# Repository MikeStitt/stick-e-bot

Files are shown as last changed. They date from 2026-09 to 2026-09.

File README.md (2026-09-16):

# stick-e-bot — a CAD course in Onshape

An introduction to Onshape, taught by building a printable stick figure robot
about 300 mm tall, with a ball-and-socket neck and hips and a ratcheting hinge at
the elbows and knees.

## Repository layout

```
CLAUDE.md                  The agreement to follow the Constitution, for AI assistants.
README.md                  This file.
build.ninja                `ninja check` — wrap, spelling, reading level and capture, in one
                           command. `ninja guides` builds the Sphinx sites.

instructions/              What a student or a teacher is handed.
  robot-guide/             The design source. make_plans.py renders every plan drawing from the
                           numbers, so a dimension is changed in one place.
  stickbot-draft9p4/       The guide in progress: fourteen tutorial pages and their frames.
docs/                      Background for those same people: how things work, what things are.
src/stickbot/              The Python, installed into .venv by `uv sync`: the four checks, the
                           design source, and the browser and API machinery. Imported by name —
                           nothing here or anywhere else touches sys.path.

.claude/rules/             The contract. Injected into an agent's context on every request.
  constitution.md          How material gets written and verified. Read first.
  parts/prose-style.md     How every word in this repository is written.
  parts/plan-activation.md How a plan becomes the active one, and how it stops being.
  active-plan.md           One import naming the plan being executed, empty when none is.
.claude/skills/            The rest of the contract. Read the one your task needs.
  onshape/                 Shared modeling and step-writing conventions.
  lesson-design/           Shared session-design rules: pacing, floor/ceiling, checkpoints, rubrics.
  modeling-practice/       The design-intent standard every reference model must meet.
  constitution-maintenance/  How the Constitution is amended, and its changelog.
.docs/                     For the people building the class, and for agents. Working notes,
                           design decisions, and the build specification under .docs/build/.
  experiments/runs/        One folder per draft: its plan, its notes, its logs, its register.
```

## Images

**A frame reaches git only by being placed on a guide page.** `.gitignore` denies raster images and
video everywhere and un-ignores exactly `instructions/*/source/images/`; a take writes its interim
capture to the session scratchpad, which is outside this tree. `src/stickbot/check_images.py` is the
*Capture is out* Quality Gate and checks that it happened, so a file added with `git add -f` is
caught too.

The repository this one replaces committed 12,977 screenshots totaling 1,651 MB because capture and
publication shared a directory. It sits beside this one and keeps that history;
[`.docs/2026-09-14-move-to-stick-e-bot.md`](.docs/2026-09-14-move-to-stick-e-bot.md) records what
moved and what did not.

## Getting set up

```sh
uv sync                            # the environment, from uv.lock
uv run playwright install chromium # separate step; uv sync does not do it
ninja check                        # wrap, spelling, reading level, capture
```

Every Python command in this repo is `uv run python …`.

## Reference models

The Onshape documents a session starts and ends from. Cite a **named version**, never the live
workspace; a workspace moves under the class.

| Document | Purpose | Link |
| --- | --- | --- |
| Instructor reference | The finished model, built the taught way | _TODO_ |
| Session 2 start | Recovery point: end-of-session-1 state | _TODO_ |
| Session 3 start | Recovery point: end-of-session-2 state | _TODO_ |
| Session 4 start | Recovery point: end-of-session-3 state | _TODO_ |

These are placeholders, and there is a known obstacle in front of them. On 2026-09-14 a second
Onshape account was given the document and workspace id of `stickbot-draft9p4` and was refused:
*document does not exist or you don't have permission to access it*. So a link here will not work
until the document is deliberately shared, and no link goes in until it has been opened by an
account without ownership rights.

## Contributing

Read [`.claude/rules/constitution.md`](.claude/rules/constitution.md) in full, then the part or
skill for your work type. Work on a feature branch; never commit to `main`; push only when asked.

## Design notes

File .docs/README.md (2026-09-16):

# .docs — working notes

Notes from building the course material and the reference model. These are **working notes, not the
contract** — the contract is [`.claude/rules/constitution.md`](../.claude/rules/constitution.md). If
a note here ever conflicts with the Constitution, the Constitution wins and the note is stale.

Each file marks what was **verified** (performed and observed) versus **unverified** (believed but
not checked), because the difference is the whole point of the Quality Gates.

This page is also the working list. Not every file in this folder is named here — the ones below
are the ones the current work points at.

## What needs doing, and what needs improving

State of play for the robot, at the end of run 2 (2026-08-11): Session 1 is
`instructions/robot-guide/source/index.rst`, a Sphinx page covering the body and the face. Part
one has been built twice, Part two once, and each was corrected after the run that tested it —
so **no part has been rebuilt from the text as it now stands**, and a run 3 would be its first
test. The run 2 model measures right — eyes r5, mouth 20.000 overall, neck Ø12 — at version
`run2-session1-complete`; the ball-and-socket and hinge joints are built at named versions too,
with ids in [run 2's folder](experiments/runs/2026-08-11-run2/README.md).

**Run 3 was launched, mis-briefed and thrown out** (2026-08-12). Its three agents read a brief
README claiming an open conflict over limb sections that did not exist; `#limbD` had been
settled at 12 the previous day. They were stopped, and the documents `ball-socket-run3` and
`lesson-run3` are deleted. The briefs have since been rewritten —
[`experiments/build-briefs/limbs.md`](experiments/build-briefs/limbs.md) replaces the four
invented limb briefs, and every numbers table carries a Source column. What the launcher does
before the next attempt is [`2026-08-12-launch-gate.md`](2026-08-12-launch-gate.md);
[`experiments/run3-launch.md`](experiments/run3-launch.md) holds the old prompts and is stale
against both.

## The big one — design intent

Every sketch in the model is built through the REST API from absolute coordinates with `constraints:
[]`. Under-defined, magic-numbered, and exactly the habit the course exists to prevent — see
[`modeling-practice`](../.claude/skills/modeling-practice/SKILL.md). The guide therefore
*demonstrates* the anti-pattern while *describing* the right thing, which is the worst combination
available.

**This is now work, not research.** `BTMSketchConstraint` and the `LENGTH` dimension were read back
off a rectangle drawn and dimensioned by driving the GUI — see [`onshape-api.md`](onshape-api.md).
Constrained sketches can be written through the API today.

Two gates when it is done: every sketch reports **fully defined**, and changing one driving variable
produces a correctly proportioned figure rather than a pile of parts. Both are checkable from a
script, so build them into the capture run rather than eyeballing them.

## Measure `#collar` from the ball's center, so `#grip` stops moving parts

**Done on 2026-08-27 as
[draft9p1p1's A2](experiments/runs/2026-08-26-draft9p1p1/plan.md), in the design source.**
Recorded here because [A2](experiments/runs/2026-08-25-draft9p1/a2-fit.md) got half of what it was
after and the other half was still available. `#collar` is now `#ball / 2 + #wall` = **9.0**, which
is the collar's own radius: the socket goes as deep below the ball's center as it is wide from the
axis. The model still has to be edited — that is Phase B. What follows is why.

`collar blank` extrudes `#grip` one way and `#collar - #grip` the other, so the socket is `#collar`
tall from a mouth at `#grip` down to a root at `#grip - #collar`. **A2 asks that a printing
clearance not ripple into any other robot dimension, and both of those ends move when `#grip`
moves.** [C2](experiments/runs/2026-08-25-draft9p1/c/c2-driving.md) drove `#fit` from 0.08 to 1 and
measured it: the socket stayed 11.000 tall at every value, and the tops of `Foot`, `Gripper` and
`u limb` each rose 2.0312 with `#grip`.

**So `#collar` is now the distance from the ball's center to the bottom of the socket**, and it
goes in `collar blank`'s second position on its own rather than as `#collar - #grip`. The root is
fixed, only the mouth moves, and the parts the socket is added to keep their dimensions when the
fit changes.

What it follows through to:

- The socket's overall height becomes `#collar + #grip` = 10.9465 rather than a constant, so the
  trade is named rather than hidden: before, the tabs kept a constant free length and the parts
  moved; now the parts keep their dimensions and the tabs' free length varies with the fit.
- `#collar - #grip` appears three times in the model and always means *the ball's center to the
  root*, so all three become plain `#collar`: `collar blank`'s second direction, the foot's
  `#collar_down`, and — inside a longer expression — `u limb`'s rod, which is
  `#limbCenter - #collar + #grip - #limbD / 2` and loses its `#grip` term.
- **No consumer sketches on a socket face**, checked over the API on 2026-08-27: `head`, `foot`,
  `u limb` and `gripper` each take the socket by `importDerived` and place it with a mate connector
  or a transform. So re-basing moves expressions and nothing else, and there is no rebuild order to
  get right.
- The slit floor does **not** follow from this on its own, and an earlier version of this section
  said it did. A2 fixes the root; the floor hung off the mouth at `#grip` and would have kept
  moving. It took [A1](experiments/runs/2026-08-26-draft9p1p1/plan.md) dimensioning the floor at
  `#ball / 4` below the ball's center to fix it, and that also
  [made the cut a slot for its whole depth](experiments/build-briefs/ball-and-socket.md).

**The test it has to pass is the robot's height**: `#fit` and `#grip` change no dimension of the
robot once the socket's root stops moving. In the design source it now passes — the figure comes
out 317.000 rather than 317.0535, and it stays there at any fit. Phase C measures the same thing at
the model.

## Carry the useful half of the old Session 1 into the new one

`experiments/session-1-layout-and-torso/` (**A**) was superseded on 2026-08-10 by the commit
that wrote `instructions/robot-guide/source/index.rst` (**B**) — *"Rewrite session 1 to start
from a design plan, and build it as a Sphinx page"*. B has had two test runs since; A has not
been touched since it was written. Before A is retired, four things in it have no counterpart in B.

**Its whole teaching half.** B has no `lesson-design.md` at all — no clock, floor, ceiling or
rubric. Worth carrying across specifically:

- **"Draw it badly on purpose."** The instructor draws visibly crooked, then the room watches
  geometry move as constraints land. B has no instructor guidance of any kind, and this transfers
  straight to B's torso rectangle.
- **The three across-the-room assessment questions**, especially the third — *can the student say
  what would happen if one driving line moved?* B's "Change one number" section already performs
  that demonstration with no assessment framing around it.
- **The ceiling items** — Equal instead of separate dimensions, deliberate over-constraint to find
  the redundant one, driving dimensions from a variable.

**Construction geometry, which B assumes and never teaches.** A teaches it — `q` to toggle, `v`
Vertical, `h` Horizontal. B uses none of them, but `index.rst:309` says *"this is the argument for
the rule about construction geometry: do not draw a construction line where a real edge already
is."* Either teach the rule in B or drop the sentence that depends on it.

**Two warnings B lacks.** `shift+s` is **Point**, not Sketch — A warns, B just says to use the
toolbar. And "the block only grew one way — Symmetric was not ticked", which is in A's failure
table and missing from B's fourteen-entry one.

**The drag test as a habit.** A makes it a ritual: every sketch, every time. B drags a corner at
Step 2 and mentions blue endpoints, but never establishes it.

**Do not carry A's "Tab, not Enter" note.** B's second test run found dimensions need **Enter** —
Escape silently discards the typed value, which produced a 34.8 mm torso instead of 48. Tab applies
only inside feature dialogs. A's version is wrong.

## Coverage and correctness

- **Nobody has walked the click-path.** A script did. Pacing, wording, whether a twelve-year-old
  finds the Depth box — all unknown until someone runs a session.
- **Steps 3 onwards are photographed by opening features for editing**, not by creating them. Same
  dialog, same real values, but never a half-finished selection. This is the main thing to revisit
  if the middle sessions feel thin. Steps 1 and 2 are driven click by click.
- **The fillet radii are the fragile dimensions.** A radius has to fit the face it rounds, so the
  guide's claim that any size of figure works with these steps is only tested at one size. Either
  test the range or stop claiming it.
- **Mirror is unverified and unused.** The build does everything twice by hand, which is the wrong
  lesson; Mirror is currently parked as a stretch task. Its `command-id` is known
  (`SKETCHMIRROR`, `mirror`), its dialog is not.
- **The appearance menu wording is unverified.** The highlight matches `[Aa]ppearance` loosely
  because the exact item text was never read.
- `README.md`'s reference-model links are still `_TODO_`. The document IDs are in
  [`project.md`](project.md).
- **`docs/` needs its second page.** The first is
  [`what-you-are-building.md`](../docs/what-you-are-building.md) — the robot, Onshape's
  vocabulary, and versions, written for a student and clean at grade 8. What is not covered
  yet: anything about printing the parts, and anything about the assembly.
- **Session 1's lesson-design exists now**, at
  [`../instructions/robot-guide/lesson-design.md`](../instructions/robot-guide/lesson-design.md),
  and it carries the teaching half salvaged from the old session. Two salvage items still belong
  in `source/index.rst` rather than the plan: the *Symmetric was not ticked* failure, and the
  decision on construction geometry — the page refers to a rule about it at line 309 and never
  teaches it.
- **The constitution review's 19 findings are unremediated.** The adversarial review ran on
  2026-08-12 against `e8508af`, `fffec7c` and `cb5ab99`, and nothing was applied — the last
  commit touching `constitution.md` or `.parts/` predates it. The findings, the three I contested,
  how a second round ruled on them, and the outstanding list are in
  [`2026-08-12-constitution-review-report.md`](2026-08-12-constitution-review-report.md). The
  cheapest item on that list is re-wrapping `constitution.md` to 100 columns: while it is red,
  `ninja check` never reaches the spelling and reading-level gates.
- **The build videos are a record of a build, not a lesson.** `instructions/robot-guide4/` now
  links a clip at the end of each block of steps, captured by `rec.py` as CDP event frames while
  the harness drove Onshape. They are honest and they are not yet teaching: the pointer jumps
  rather than moves, values appear in boxes already fully typed, there are long dead waits where
  the harness was blocked on a server round trip, and nothing names what is happening or why.
  The link text says *similar steps* because that is all they are — the clip covers the same
  ground as the pictures above it, not the same clicks in the same order. What would make them
  work for a student: a pointer that travels and pauses where a hand would, typing shown as
  typing, the dead time cut, a caption or a title card per step, and a decision about whether
  each clip covers one step or one section. Until then the pictures are the instruction and the
  clip is a second look. See
  [`experiments/runs/2026-08-19-run8p1/register.md`](experiments/runs/2026-08-19-run8p1/register.md).
- **The reviewer pass has not been run.** A different review from the one above, and Phase 3 of
  the reorganization. A reading pass, not a script: **Fable** reads the repository's prose —
  `.claude/rules/`, `.claude/skills/`, `instructions/`, `docs/`, `.docs/` and both READMEs — and
  flags three things.
    - **Unprofessional statements.** Snark, in-jokes, dismissiveness — anything that would not
      survive being read aloud to the class, or to a parent.
    - **Judgments based on age.** Text that sorts people by age and then uses the sorting to
      decide something. The same move made with grade level is in scope.
    - **Judgments based on status.** The same move made with standing rather than age —
      seniority, credentials, prior tool experience, or whether someone counts as a beginner.

  **What is flagged** — an age, grade, or standing substituting for a capability, an audience, or
  a permission. **What is not** — naming who is actually in the room. "Students range from
  middle-schoolers who have never opened a CAD tool to high-schoolers with some Fusion behind
  them" reports the roster. "A fourteen-year-old would not follow this" judges a person by their
  age. The first is a fact about the class; the second is a guess about a reader.

  **What it produces.** Every file is committed first, so Fable's changes land as a clean diff
  against a known state. Fable then edits in the working tree — the diff is the proposal — and
  writes `.docs/<YYYY-MM-DD>-professional-review-report.md` recording what it changed and why.
  **Nothing it writes is adopted by being written**: the diff gets read hunk by hunk, keeping what
  is right and reverting what is not, and the report is what explains a hunk when the change alone
  does not.
- **The explanatory sketches are not derived, and two of them argue for a decision rather than
  describing the design.** `experiments/sketches/`'s three studies type their inputs where the
  hinge review generates everything it shows. What to do about that, and the distinction between a
  figure that must be regenerated and one that must not, is in
  [`2026-09-16-derived-figures.md`](2026-09-16-derived-figures.md).
- **Four Stage 5 teaching routes lost their home when the limbs became cylinders.** `#limbD` is
  12 and every limb is a Ø12 cylinder, so the limb rows in the Stage 5 build order —
  [`robot-build-plan.md:609`](robot-build-plan.md) and `:611` — no longer describe a part anyone
  will model. What that costs, against the coverage table:
  - **Parallel** (`:689`) and **Perpendicular** (`:690`) are earned only in **set-piece 1**, the
    sloppy quadrilateral squared by constraints, which was the shin.
  - **Sketch Fillet and Chamfer** (`:674`) is earned only on that same quadrilateral's corners.
  - **Loft** (`:707`) is earned only on the upper arm's ellipse-to-rounded-rectangle change of
    section.
  - **Ellipse** (`:665`) and **Lines and Rectangles** (`:661`) survive — the eyes and the torso
    rectangle each carry them without a limb.

  Each of the four needs one of three answers: rehome it on a part that still needs it, teach it
  on a scratch sketch that is not a robot part, or drop it from the curriculum and say so. This
  is a curriculum decision. **Do not shape a limb to keep a tool** — where a route cannot produce
  a Ø12 cylinder, the route gives way. See
  [`experiments/build-briefs/limbs.md`](experiments/build-briefs/limbs.md), which is written not
  to answer this.
- **Two constitution amendments are pending, both from the same failure.** Read
  [`constitution-maintenance`](../.claude/skills/constitution-maintenance/SKILL.md) before making
  them.
  - **Reading the specification is a verification step.** *Verification is evidence, not
    assertion* covers building the thing and looking at it; it does not say that the relevant
    specification and requirements MUST be read first. Add that, and attach it to the same list
    of activities as Working Rule 1 — before you plan, write, model, code **or direct**.
  - **`direct` belongs in every enumeration of what an agent does.** Working Rule 1 says "think
    before you write, model, or code"; the Quality Gates and *Verification is evidence* are
    written for someone doing the work with their own hands. Directing a subagent is none of
    those verbs, and it is how most of the work now happens. Every list of activities in the
    Constitution needs it.

  *Why:* three agents were launched against briefs written without reading the settled spec. The
  limbs had been fixed at Ø12 the previous day — decided in conversation, recorded in the hinge
  brief, in no document the launcher read — and the briefs invented sections that contradicted
  it. Nothing verified the direction, because no rule treats directing as work.
- **Session 1's two documents are reconciled.** `instructions/robot-guide/` supersedes
  `experiments/session-1-layout-and-torso/` — what to salvage from the older one is above, under
  *Carry the useful half of the old Session 1 into the new one*.

## Pipeline improvements worth making

- **`show_result` reopens the document** to get a known camera, which costs a 16 s page load each
  time. Correct, but it is most of the runtime of a capture run. A cheaper deterministic camera
  would pay for itself.
- **Onshape rate-limits hard.** A burst of feature writes earns a 429 on that endpoint family that
  took over an hour to clear on one occasion, blocking all capture work. Writes are paced now, but
  do not plan a working session around many rebuilds.
- **Handling a 429 is written, and the history says why it took eight tries.** Done on 2026-08-28.
  The rule is [`onshape`](../.claude/skills/onshape/SKILL.md) § *Read what a refusal says before
  waiting on it*; the mechanism is `api()` in
  [`../src/stickbot/onshape_session.py`](../src/stickbot/onshape_session.py), which now keeps the
  response headers, honors a short `retry-after`, and raises at once rather than spending a ladder
  to discover the answer is hours away.

  **Verified against a live 429 on 2026-08-28.** `features` answered `retry-after: 522` with
  `x-rate-limit-remaining: 0`, and `api()` raised in 0.10 s naming both, where the old ladder
  would have spent 110 s and five requests to reach a message that was wrong on two counts. In
  the same pass `bodydetails`, `parts` and `assemblies` answered 200 with 486, 500 and 1000 calls
  left, which is the per-family limit measured from the healthy side. The sweep of what came
  before:

  - **08-10, `5263ee7`, the client's `api()`.** Assumed one kind of 429, minutes long, and
    laddered 5 s to 480 s, 955 s in all. It was the first handling of any kind: before it a 429
    read as a `DELETE` that quietly did nothing and a feature list with no `features` key.
  - **08-10, `b5d2aec`, the same function.** Cut the ladder to 5, 15, 30, 60 because *"an
    unbounded backoff turns a rate limit into something indistinguishable from a freeze"*. The
    reasoning holds. The message did not: it hard-coded *"account-wide on the feature endpoints
    and clears in minutes"*, and that sentence is what every later reader believed.
  - **08-10, `be1b460`, `wait_and_capture.py`.** Polled every 60 s and gave up after an hour. A
    runner that waits, for a limit whose answer is a different route.
  - **08-10, `08a50d2`, the same runner.** Polled every 300 s and gave up after six hours, on the
    theory that the polling itself was holding the block open. Six hours does not outlast
    eighteen. Retired on 08-12 with the pipeline that used it.
  - **08-13, `60377ea`, `design-into-cad.md`.** Right, and complete: a daily quota, `retry-after`
    in the tens of thousands of seconds, counting down with the clock, one endpoint throttled
    while the rest answer, so move to the GUI. Prose only. It landed in `.docs/experiments/`,
    which the Constitution files as archive, and no code and no part changed.
  - **08-14, `013b57f`, `onshape-gui-howto.md`.** Took 83 s from the one end-to-end pair in run
    3's torso log and made it the recovery time. One measurement of the short mode, generalized.
  - **08-14, `905fff0`, the same file, hours later.** Corrected itself: two kinds, waiting inside
    a session worked neither time, plan a route that avoids `/features`. Still prose only.
  - **08-24, `15441c6`, tutorial 11's build log.** Backed off every time and it did not clear, so
    `featureStatus` was never read; the acceptance check fell back to looking for error badges in
    the tree frame.
  - **08-27, draft9p1p1 Phase C.** Measured all of it from scratch again, and re-planned a phase
    around never touching `features`.

  **The cause is not that nobody knew.** It was right in the tree on 08-13, fourteen days before it
  was measured again, and re-derived on 08-14. What failed each time is that the finding landed in a
  working note while the client went on asserting the opposite in the message it raised, and the
  client is what the next person read. A finding about a tool has to reach the tool.
- **Arc and circle have never been drawn from a script.** Rectangle and dimension have. Same shape
  of problem, and needed if more steps are to be driven click by click.
- **The browser profile lives in a session scratchpad**, so the login does not survive. Move it
  somewhere durable, or get an API key from `dev-portal.onshape.com` and stop depending on a
  signed-in window.
- Three stale Onshape documents can be deleted once nothing points at them — see
  [`project.md`](project.md).

## Future work — print orientation, and the edge treatments that depend on it

**Not adopted. Recorded because it blocked a decision we tried to take on 2026-08-11.**

We went looking for a standard fillet size for a 0.4 mm nozzle and found the question is not
answerable on its own. Every useful source qualifies its advice by which way the feature faces
on the plate:

- **Vertical corners are already filleted at about 0.2 mm** — half the nozzle diameter — whether
  drawn or not. Protolabs Network: *"Because FDM printing nozzles are circular, corners and
  edges have a radius equal to the nozzle size."* So nothing below ~0.4 mm is worth drawing.
- **Downward-facing fillets print badly** and want to be chamfers instead. Hydra Research: *"do
  not use downward facing fillets… they may come out with poor aesthetic/surface quality."*
- **Edges on the build plate want a 45° chamfer**, sized 0.3–1.0 mm depending on layer height.

Candidate numbers, if we ever adopt them: **0.5 mm × 45° for a cosmetic edge break, R1.0 as the
minimum drawn fillet, and nothing under 0.4 mm drawn at all.**

**Why it is not adopted:** "upward" and "downward" are properties of the print, not of the
model. Until each part carries a **declared print orientation**, an edge rule cannot be applied
— the same fillet is fine on one face and ugly on the opposite one.

**The bigger instance of the same problem is structural, not cosmetic.** A snap-fit tab flexed
about an axis parallel to the layer lines peels them apart and fails well below the calculated
strain; flexed within a layer it does not. That applies directly to the ball socket's four tabs
and to the hinge's sprung ears, and neither brief says which way up the part is printed. The
hinge report's 2.2 % ear strain and the socket's tab calculations both quietly assume the
favorable orientation.

**What adopting it would take:** a declared orientation per part, shown on the parts drawing;
edge treatments chosen per edge against that orientation; and the tab-bearing parts oriented so
their tabs flex in-layer.

Sources: [Protolabs Network](https://www.hubs.com/knowledge-base/how-design-parts-fdm-3d-printing/),
[Hydra Research](https://www.hydraresearch3d.com/design-rules),
[NExT Lab](https://ms-kb.msd.unimelb.edu.au/next-lab/3d-printing/design-guidelines),
[3DVerkstan](https://support.3dverkstan.se/article/38-designing-for-3d-printing).

## Decisions taken, worth not re-litigating

- **Highlights come from the DOM.** No pixel coordinates anywhere. This is what keeps the
  annotations correct across window sizes and Onshape's redesigns, and it was the single most
  useful decision in the project.
- **Every shot verifies itself.** A click that should select something is checked against Onshape's
  own measurement readout; a highlight target that is not on screen raises rather than quietly
  vanishing.
- **The builder only ever goes forwards.** Rebuilding the figure per step would be ~500 feature
  writes and a guaranteed rate limit; building forwards is 22.
- **Screenshots notice, measurements conclude.** See
  [`verification-lessons.md`](verification-lessons.md) — three wrong diagnoses in one session came
  from treating a surprising picture as evidence of its own cause.

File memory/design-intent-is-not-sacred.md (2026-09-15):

---
name: design-intent-is-not-sacred
description:
  "No design source outranks another; a constraint that is causing disproportionate work is itself
  the suspect."
metadata: 
  node_type: memory
  type: feedback
  originSessionId: c7e95b50-7b3c-4747-a656-ece9f33b51c4
  modified: 2026-08-13T20:02:09.527Z
---

Never rank the design sources against each other — sketches, briefs, and whether the thing
actually assembles and articulates all sit at one level. When a requirement is costing
disproportionate work, treat the requirement as a candidate for change, not just the work.

**Why:** ranking makes one source unchangeable, and an unchangeable source turns every conflict
into work squeezed around it. The reference robot's "150 mm tall" is the worked example: while it
was a requirement the design bent to reach it, and once the parts were allowed to fall where the
joints put them the problem got smaller and the answer got honest. How much work a constraint is
causing is evidence about the constraint.

**How to apply:** when a conflict appears, say what it would cost to change each side, including
the requirement itself — do not silently treat the stated number as fixed and optimize around it.
Present changing the requirement as a real option with its price. Related: the user still decides
— see [[instructions-state-facts-not-importance]] and [[cad-models-need-design-intent]], which is
about a model surviving a driving-dimension change, not about which dimension is allowed to drive.

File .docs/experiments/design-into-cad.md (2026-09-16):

# Getting the design into the CAD

After run 3 we changed the initial sketches and then the briefs. The design moved and the CAD did
not. The sketches were re-drawn, the shoulder was angled, the
hinge was rebalanced, and the briefs were corrected against measurement — none of which reached a
part studio. Run 4 copied run 3's geometry, added mate connectors, and assembled it; every sketch
and extrude in it is still run 3's. See
[`runs/2026-08-13-run4/build-notes.md`](runs/2026-08-13-run4/build-notes.md).

This file is the plan for closing that gap. It is deliberately two sections in one: a **high-level
plan** that does not change, and a **low-level plan** whose steps are chosen while the work is
running, from what each part turns out to contain.

It is the procedure, not the checks. [`build-and-verify.md`](build-and-verify.md) is the wave
cycle, [`build-briefs/README.md`](build-briefs/README.md) is what a part is held to, and the
Constitution governs sessions, versions, and branches.

## Done means

Every number and every shape the sketches and the briefs assert is **either in the CAD or written
down as an unresolved conflict**, and the assembly is rebuilt from the repaired parts.

We examine each part and the assembly in detail until we understand what every one of its features
is. We confirm from those features that it looks like the part the sketches and briefs asked for,
and specifically that it matches the developmental sketches the briefs were constructed from. We
measure the dimensions and confirm they match the briefs and the initial sketches.

For the assembly we confirm that its dimensions, orientation, parts and mates are right against
the briefs and the initial sketches.

---
# The high-level plan

## Authority

When two sources disagree, this is the order, and it does not get renegotiated per part.

| Rank | Source | What it settles |
|---|---|---|
| 1 | [`sketches/`](sketches/), [`build-briefs/`](build-briefs/), our evaluation of if the robot assembles and articulates per the design intent | pose, station, which way a part faces, what the figure looks like, each part's own numbers and its acceptance checks |
| 2 | the CAD | **nothing** — it is the thing under test |

**Sketch and brief can disagree with each other**, and when they do neither wins automatically —
that is a conflict for you to resolve in a way that achieves our design intent.

**They share a rank deliberately.** Ranking them would make one of them unchangeable, and an
unchangeable source turns every conflict into work squeezed around it. The figure's height is the
worked example: while 150 mm was a requirement the design bent to reach it, and once the parts
were allowed to fall where the joints put them the problem got smaller. No part of the design
intent is sacred. **How much work a constraint is causing is evidence about the constraint**, not
only about the work.

**A brief row marked *measured* or *built* is a record, not a target.** Some rows came back out of
the CAD rather than out of the design — the foot's collar reads `5.5 → 7.35 | plan, then built`,
because the collar's proud length is set by the plate and the foot cannot reach 5.5. Repairing to
a row like that models backwards from an accident, or chases a number the part cannot hold. Read
the **Source** column first: `plan` and `derived` are targets, `proposed` is a target nobody has
challenged, and `built` and `measured` are history.

## The phases

Mark each phase 'Done.' as completed.

0. **Copy.** Done. Nine documents copied to run 5, recorded in
   `runs/2026-08-13-run5/run5-documents.json`. All of this work happens in run 5.
1. **Gather a list of changes.** Done. `git diff 5ff5f3d..HEAD` over the briefs and the
   sketches, written to `runs/2026-08-13-run5/changes-since-run3.md`.
2. **State the target.** Done. `src/stickbot/make_target.py` writes
   `runs/2026-08-13-run5/target.json` from **both** sources: every design constant out of
   `make_plans.py` by introspection, and every numbers-table row out of the briefs by parsing
   — 91 numbers, the figure's stations, each joint in the frame its part is modeled in, and 64
   brief rows carrying their **Source**, classified target against record. Nothing is typed in,
   so neither half can drift. Briefs with no numbers table are named rather than dropped.
3. **Audit.** Done. All six parts measured and rendered in four views;
   `runs/2026-08-13-run5/audit.md` carries the deltas classified by route, and
   `measured.json` the raw faces and solids. Two parts need no repair.
4. **Deconflict.** Done. `runs/2026-08-13-run5/deconflict.md` — the hinge stack checked
   surface by surface across both halves, four things resolved, two registered.
5. **Repair.** Done. S1 through S5, each measured on solved geometry and written up in
   `runs/2026-08-13-run5/repairs.md`.
6. **Evaluate the parts.** Done. The three axes below, on the parts, in
   `runs/2026-08-13-run5/evaluation.md`.
7. **Re-assemble.** Done. Fourteen instances from `run 5` versions, thirteen mates, all `OK`,
   published as the `run 5 assembled` version of `lesson-run5`.
8. **Evaluate the robot.** Done. Same file — every station matches `make_plans.py`.
9. **Register.** Done. `runs/2026-08-13-run5/register.md`.

Run the phases in order, in this top-level agent, which does all of the CAD itself. It may give
analysis, research, evaluation and thinking to sub-agents.

**Do not stop between phases.** Finishing a phase is not a place to report and wait — mark it
Done, commit, and start the next one in the same breath. The run goes from phase 0 to phase 9
without being told to continue. This holds whether or not anyone is watching: an unattended run
and an attended one differ in who is reading, not in whether the work proceeds.

There is no question worth stopping for, because there is somewhere else for every question to go.
A conflict goes in the register with what it turns on and what the options cost; a decision that
is not mine gets its cheap answer written down and the work routes around it. Stopping to ask
converts a question that costs a paragraph into one that costs the rest of the run.

## The three evaluation axes

The user's three questions, and how each is actually answered rather than asserted.

| Axis | Answered by |
| ---- | --- |
| **Matches the sketches** | station and pose measured off the assembly — joint centers, overall height, arm span, which plane each part's length runs in — compared against `make_plans.py`'s own numbers, not against a reading of the drawing |
| **Matches the briefs** | each brief's *Acceptance checks* section, performed and recorded per part. They exist for this and were written to be measured, not inferred |
| **Works as a printable robot** | the three sub-axes below |

"Works" is the one that has no checklist yet, so it gets one:

- **Printable.** No wall below one nozzle width anywhere in the part; overhangs and bridges
  identified per part with the print orientation named; no feature that only exists in the model
  because the model has no gravity.
- **Assemblable.** Every ball can enter its socket — which means every socket collar is slit —
  and every press fit has an interference that is deliberate and stated. A joint that cannot be
  put together once is a failure even if it measures perfectly.
- **Functional.** Each joint reaches the range the sketch draws it at without fouling the part
  next to it, and each spring feature sits far enough below PETG's yield to survive a print that
  came out thick. The ranges and the margins are in the briefs; this axis is where they get
  checked against the assembled geometry rather than against a hand calculation.

## What gets resolved and what gets written down

**I resolve** a conflict when all three hold: the brief row is a target rather than a record, the
change moves no driving variable, and the fix does not trade one stated goal against another.
Slitting a collar, changing a thickness the brief already settled, rebuilding a feature to numbers
that are already derived — those are work, not decisions.

**I write down** — and do not decide — anything that moves a driver (`#torsoH`, `#hipHalf`,
`#legX`), anything where the sketches and the briefs disagree with each other, anything that
changes the part count or introduces handedness, and any fix that buys one axis by spending
another. Each entry carries what is known, what it turns on, what the options cost, and the cheap
answer, per the unattended rule in [`build-and-verify.md`](build-and-verify.md).

**A third case exists and has bitten once already:** work I did not attempt, recorded as though it
had been a decision. It is neither resolved nor a genuine conflict, and calling it parked is a
false record. If it was not attempted, the register says so in those words.

## Where the work lives

Repairs go into the **run 5 documents' workspaces**. Run 4 is left alone: it is the record of what
an assembly built from unrepaired parts measured, and run 5's instructions are what the teacher
and student will follow, so run 5 is the copy worth having.

---

# The low-level plan

The high-level plan is fixed. Everything from here is chosen at audit time, because what a repair
costs depends entirely on how the feature that needs repairing was built — and that is not known
until it is read.

## Repair routes

Every delta the audit finds is classified by the route that can fix it. Which route applies is a
property of how the part was built, not of the delta, and it is read off the feature tree.

| Route | Applies when | Cost |
| ----- | --- | ---- |
| **Variable** | the number is driven by a variable in the studio | one edit, propagates |
| **Feature parameter** | the number is a feature's own parameter — an extrude depth, a fillet radius, a pattern count | one call per feature |
| **Sketch entity** | the number lives in a sketch's geometry or its dimensions | the sketch's entities and constraints are rewritten together |
| **New feature** | the geometry does not exist at all, as with a collar that was never slit | insert at the right point in the tree, not at the end |
| **Rebuild** | the construction cannot express the target — a solid blade that has to become two tabs | delete and re-author the affected span |
| **GUI** | the API route fails, or the edit is faster by hand | screenshot it; run 5 needs the pictures anyway |

## The steps

Written by phases 1–4 and worked through in phase 5. Reasoning is not repeated here — each step
points at the file that carries it. Mark a step **Done** as it completes.

### S0 — prove the sketch-entity route — **Done**

Proved on `ball-socket-run5`, which no assembly instance references. The route works, and it is
not where it looks like it should be.

A sketch is a `BTMSketch-151`. Its `parameters` carry only `sketchPlane` and `disableImprinting`;
the geometry lives in the feature's own `entities` and `constraints` fields, in **meters**.

**Edit the dimension constraint, not the entity.** Setting `entities[0].geometry.radius` from
0.0047 to 0.0055 answered 200 and read back 0.0055 — and moved nothing, because a `DIAMETER`
constraint drives that circle and the solver puts the geometry back. Setting that constraint's
`length` expression from `9.4 mm` to `11 mm` moved the volume 2305.3461 → 2432.2462, and
restoring it came back to 2305.3461 exactly.

**So the entity's stored radius is stale cache, not the solved value**, and reading it back proves
nothing. This defeats read-back-plus-200 as a check: both passed on the edit that did nothing.
Only the measured quantity caught it. Every step below measures something that must move.

### S1 — torso: the shoulder stud and the neck boss — **Done**

Per [`audit.md`](runs/2026-08-13-run5/audit.md). Hardest, so it goes first. Built and measured in
[`repairs.md`](runs/2026-08-13-run5/repairs.md), which also carries the four findings. S1e closed
the other way: the neck boss cannot buy the tilt it exists for, so it is not built.

- **S1a** Shoulder stud on a doubly-rotated axis: 53° below horizontal, 30° toward the front,
  rooted on the side face at x = ±18, z = +20. The part has no plane for this — it needs a mate
  connector or a construction plane before it needs a sketch.
- **S1b** Ø8 boss, 8 long, coaxial with the stalk; then Ø3 stalk for the last 5; then the Ø6 ball.
  Ball lands at (±24.775, −3.912, +9.618).
- **S1c** Cut the boss flush where it crosses the torso's top face at z = +24.
- **S1d** Mirror to the left shoulder — mirror the part, not the feature.
- **S1e** Neck boss Ø12 on the top face, on the axis. New feature.
- **S1f** Measure the least clearance between the upper arm and the torso across the full
  ±37.09° swing. This is the check the geometry exists to pass.

### S2 and S3 — the two limb halves, together — **Done**

Measured in [`runs/2026-08-13-run5/repairs.md`](runs/2026-08-13-run5/repairs.md). S3c turned out to
be two features rather than one, and that record says which.

They meet inside one joint and the stack is checked in
[`deconflict.md`](runs/2026-08-13-run5/deconflict.md). Repairing one alone leaves a joint that
cannot close, so neither is Done until both measure.

- **S2a** `limb-socket-clevis`: slot half-width 1.8 → 2.8, so the ear becomes 3.2.
- **S2b** Remove the ear's outer planes at ±3.0 and ±2.5 — the ear's outer surface is the Ø12
  cylinder and has no outer plane at all.
- **S2c** Round ends r5.81 → r6, putting the fork tip at z = −30.
- **S2d** Stub inner face ±1.0 → ±2.0, keeping it 0.8 proud of the new ear face.
- **S2e** Slot root to z = −13, which is 11 behind the pin axis.
- **S3a** `limb-blade-ball`: blade half-thickness 1.5 → 2.5.
- **S3b** Detent valley floors ±1.05 → ±2.05; land follows the blade face to ±2.5.
- **S3c** Round end r5.81 → r6, blade tip at z = +6, blade's limb ending at z = −10.
- **S3d** The slit: 0.8 wide, 16 deep, down the blade's middle, open at the tip, leaving two 2.1
  tabs. New feature.

### S4 — foot — **Done**

Measured in [`runs/2026-08-13-run5/repairs.md`](runs/2026-08-13-run5/repairs.md).

- **S4a** Re-sketch the outline with its length along **Y**, symmetric about the Right (YZ) plane
  by `Symmetric` constraint rather than by dimensioning both sides.
- **S4b** Four relief slits, 0.8 wide, cut through the collar for its **whole 7.35** proud length
  — the slit follows the collar it is cut into, not `COLLAR_L`.

### S5 — the brief that is wrong, not the model — **Done**

- **S5a** `hinge.md` says run 3 built 13 detent valleys. It built 24 a side, and `STEP` 15 divides
  360 into exactly 24. Correct the brief.

### S6 — versions — **Done**

One named version per repaired part, cut after its measurements pass. The assembly cites versions,
never workspaces — so the two parts run 5 did not touch, the head and the hand, get one as well.
All six are named `run 5` and their ids are in
[`runs/2026-08-13-run5/run5-documents.json`](runs/2026-08-13-run5/run5-documents.json).

### S7 — assembly — **Done**

Rebuilt from the new versions and re-mated: thirteen mates, all `OK`. The foot's 90° turn came out,
because S4a puts the part's length on the axis the assembly wanted. The shoulders needed two new
mate connectors, placed in the assembly rather than the torso. Measured in
[`runs/2026-08-13-run5/repairs.md`](runs/2026-08-13-run5/repairs.md).

### S8 and S9 — evaluate and register — **Done**

The three axes on the parts and then on the robot are in
[`runs/2026-08-13-run5/evaluation.md`](runs/2026-08-13-run5/evaluation.md), and what was resolved,
what was not, and what was never attempted are in
[`runs/2026-08-13-run5/register.md`](runs/2026-08-13-run5/register.md).

## What the API is known to do

Stated precisely, because it was once asserted here more broadly than it had been tested.

| Operation | Endpoint | Status |
| --- | --- | --- |
| add a feature | `POST .../partstudios/d/{d}/w/{w}/e/{e}/features` | **proven** — run 4's mate connectors |
| update a feature's parameters | `POST .../features/featureid/{fid}` | **proven** on an extrude — see below |
| rewrite a sketch's entities and constraints | same endpoint, different payload | **proven** — see below |
| insert a feature mid-tree | `POST .../features/rollback`, then add, then move the bar back | **proven** — S1 put four features between a revolve and its mirror |
| read every feature's parameter spec | `GET .../featurespecs` | **proven** — how S1 learned `transform` without opening the GUI |
| delete a feature | `DELETE .../features/featureid/{fid}` | proven on assembly features; the id must be percent-encoded, because ids contain `/` |
| read every face's surface, radius, axis, area and box | `GET .../parts/d/{d}/w/{w}/e/{e}/partid/{p}/bodydetails` | **proven** on all six parts, and **not rate limited** while `featurescript` was 429 — it answered most of the acceptance checks |

**A feature is always added at the rollback bar**, and the bar has its own call. `rollbackIndex`
passed in the add body is ignored without complaint — the feature lands at the end and the answer
is still `200`.

The update test, run on the `ball-socket` study document because no assembly instance references
it: the `Socket collar` extrude's depth was round-tripped unchanged, then driven 1.35 → 9.5, then
restored. All three answered `200`, the parameter read back changed, and total solid volume moved
2305.3461 → 2681.2635 → 2305.3461 mm³. The study is back where it started.

**A `200` is not the test.** The first attempt measured overall height, which sat at exactly 150.0
before and after because a reference body sets it — the call looked successful and proved nothing.
Every repair re-reads the changed parameter *and* measures a quantity that must move.

### Sketches

A sketch is a `BTMSketch-151`. Its `parameters` carry only `sketchPlane` and `disableImprinting`;
the geometry lives in the feature's own `entities` and `constraints`, in **meters**.

**Edit the dimension constraint, not the entity.** Setting `entities[0].geometry.radius` from
0.0047 to 0.0055 answered 200 and read back 0.0055 — and moved nothing, because a `DIAMETER`
constraint drives that circle and the solver puts the geometry back. Setting that constraint's
`length` expression from `9.4 mm` to `11 mm` moved the volume 2305.3461 → 2432.2462, and restoring
it came back to 2305.3461 exactly. **The entity's stored radius is stale cache, not the solved
value**, so reading it back proves nothing — both checks passed on the edit that did nothing.

A whole profile can be replaced in one call, entities and constraints together. Two things bite:

- **A line's stored `pntX/pntY/dirX/dirY` is the infinite line; the ends come from the
  constraints.** Author the loop and let it solve.
- **A distance constraint carries a side.** Copying one and swapping which end it measures from
  put a line 16 mm from where it was asked to go, and the sketch still solved, and every feature
  still read `OK`. It was the region's *area* that gave it away.

## Building it through the GUI instead

The feature endpoints are on a **daily quota**, and S1 spent it. `GET` and `POST` on `.../features`
answer `429` with `retry-after` in the tens of thousands of seconds and `x-rate-limit-remaining: 0`,
and that counter runs down with the clock rather than resetting on a retry — so backing off inside
a request does nothing. Only that endpoint is throttled: `featurescript`, `massproperties`,
`shadedviews` and the document endpoints all still answer `200`, **so the build moves to the GUI
and the checking stays exactly where it was**. Nothing about the standard of proof changes.

The app is driven on 9223 through Playwright over CDP, the same connection the REST calls use.

- **The feature list's context menu is the whole toolkit.** It carries `Rename`, `Edit…`,
  `Suppress`, `Roll to here` and `Delete`. Two things hide it: it only opens on the row's
  `span.os-list-item-name`, and it does not open at all while a feature dialog is up — the
  right-click is swallowed and the list looks like it has no menu.
- **The rollback bar cannot be dragged.** `div.ns-list-item-rollbackbar` has no event listeners at
  all; its holder has `click` and feature rows have `click`, `dblclick`, `mousedown`. Every
  synthetic drag on it fails while looking like it worked, because the feature list and the parts
  list share a splitter that resizes under the same gesture. **`Roll to here` on the context menu
  is the way to insert mid-tree.**
- **Read a dialog by what its controls say, not by where they sit.** Ticking one option reflows
  everything below it, so a coordinate captured before a click is wrong after it. Checkboxes are
  `label.os-param-checkbox`, numbers are `input.os-param-number`, and the icons are `use` elements
  keyed by href — `#svg-icon-flip-direction` beside the end-condition dropdown, and
  `#svg-icon-ok-button` to accept. Some carry `href` and some `xlink:href`; read both.
- **"Direction" does not mean reverse.** In Extrude it opens a query for a custom direction entity,
  and leaving it empty puts the feature in error. Reversing is the flip icon by the dropdown.
- **A dialog does outlive the session that opened it.** An earlier note here said the opposite. A
  sketch stayed open across a dozen reconnections while it was drawn, dimensioned and accepted, so
  a step can be taken and then read off a screenshot before the next one. What does not survive is
  a half-typed value: `Escape` closes the field and leaves the dimension at its old number.

Drawing a sketch, rather than editing a dimension in one, adds these:

- **Pick the model out of the way first.** Hide the part and any construction plane whose edge-on
  trace lands near a sketch line. Nothing in a sketch can be selected by name, so an ambiguous
  pixel is an ambiguous pick, and the tree tells you afterwards what you actually got.
- **A sketch has no axis of its own to select.** The vertical line through the origin is the
  **Front plane's trace**, and that is what a `Symmetric` constraint ends up mirroring about — which
  is the right answer here, because the Front plane *is* the blade's mid-plane.
- **The visibility eye is only in the page while its row is hovered.** Hover the row, then click
  `span.ns-visibility-icon`. Without the hover the element does not exist and the click times out.
- **An under-constrained sketch moves when you drive one of its dimensions.** Setting the slit's
  root to 10 shifted its free sides from ±3.46 to ±2.60 and its free top with them. Re-read
  coordinates from a fresh screenshot after every dimension, not once at the start.
- **A dimension between the rectangle's two sides came back with no field at all**, twice, from two
  different pick points; the same two lines each took a dimension against the Front plane's trace
  on the first try, plane picked first. With `Symmetric` already holding, one half-width against
  the trace is enough.
- **`has_text` matches a substring.** Asking for `Limb` opens `Limb section`. Match the whole name.

### Everything a repair is checked against must be measured

Nothing above is trusted from a status. The `200`, the parameter read-back, and a tree of `OK`
feature states have each passed, separately, on a change that moved no geometry. Every step
measures a quantity that must move.

## Order of work

1. **Prove the sketch route first**, on a study document, before any real repair depends on it.
   This is not "do the easy work first" — it is one throwaway experiment that decides whether
   most of the repairs are API edits or GUI work, and it is cheap only while nothing rides on it.
2. **Hardest first.** Solve the hard thing while the clock and the options are both open, so that
   easy work done early does not constrain it.
3. **Joint-carrying parts before joint-consuming parts.** A socket or a hinge that changes moves
   every part that mates to it; a part that only carries a joint moves nothing.
4. **The assembly after all of them**, never in the same sitting as a part it assembles.

## Checkpointing

Each part is a checkpoint: version cut, notes appended, register updated, committed. The work must
survive being stopped between any two parts, because it will be.

## Nothing stops the run

Every phase runs to its end, every step in it, on every part. A finding is recorded and the work
continues. **It never ends a step, a part, or the run.**

This is not a tolerance for sloppiness, it is the opposite. Stopping early is a judgment about
what "done" is worth, made by whoever is holding the tools, and it is the one judgment this plan
does not delegate. A robot whose parts collide is an acceptable outcome when the collision is
written down and everything else was carried through and checked. An audit that halted at its
first finding is not, because the problems it never reached are invisible, and nothing in the
record shows that nobody looked.

Run 4 is the worked example: three fixable defects found, the bar judged unreachable, the
remaining parts never examined — so what else is wrong with them is still unknown.

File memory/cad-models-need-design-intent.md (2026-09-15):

---
name: cad-models-need-design-intent
description:
  "Onshape models for this course must be built from constraints and relationships, never absolute
  magic coordinates"
metadata: 
  node_type: memory
  type: feedback
  originSessionId: f7a2d0bd-c646-4b69-9103-9c444fdbf1e2
  modified: 2026-08-09T20:36:50.904Z
---

The user (Mike) expects CAD models here to be built the way a person actually models: first
sketch is a center-point rectangle on the origin, and every later sketch, extrude
or revolve is tied to existing geometry through projected edges and constraints
(Coincident, Collinear, Equal, Symmetric) plus named variables. No magic numbers,
no independently authored absolute coordinates — a web of relationships.

**Why:** the deliverable is a class teaching people to CAD. A reference model made
of typed coordinates looks correct but teaches the exact habit the course exists
to prevent, and it teaches it invisibly. It also shatters the moment one driving
dimension changes.

**How to apply:** treat "every sketch reports *fully defined*" plus "change one
driving variable and the model updates sensibly" as the acceptance gate for any
model, not just "the render looks right". When an API or scripting path makes raw
geometry easy and constraints laborious, do not let that shape the model — that is
the tool dictating pedagogy. Related: [[onshape-api-via-browser-session]].

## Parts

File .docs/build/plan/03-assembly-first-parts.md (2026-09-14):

# 3. The assembly, with two parts in it

Starts from a torso and a head in two Part Studios. Ends with an assembly named `stickbot`, on the
first tab, holding both.

**A student sees a robot here, three tutorials in.** Everything after this adds to something that
already looks like the thing being built.

## The steps

| Identifier | The move | `creates` |
| --- | --- | --- |
| `cad.assembly.place_body_head` | insert the torso and the head from the workspace | `torso <1>`, `head <1>` |
| `cad.assembly.pose` | drag the head up 90 mm, so it floats clear above the torso | nothing |
| `cad.assembly.rename` | name the assembly `stickbot` | nothing |
| `cad.assembly.first_tab` | drag it to the first tab | nothing |

**Nothing is mated yet.** The head has no socket and the torso has no stud, so there is nothing to
mate to. Both parts float, and saying so out loud is better than a student wondering what they got
wrong.

**Insert drops both instances at the origin, which buries the head inside the torso.** No later
step depends on how far the head is dragged up; what matters is that the picture reads as a robot
before the page claims a student can see one. Dragging it is also the first time a student moves an
unmated instance, which is the thing tutorial 7 then takes away with a mate.
[`../drafts.md`](../drafts.md) § *The requirements* carries this as `req.model.posed`.

**The drag ends in a box, so the page names a number after all.** Letting go leaves a distance field
holding the free-hand figure, and typing over it moves the instance exactly that far. 90 mm is what
the page teaches, which leaves the head's underside 6 mm clear of the torso's top. A typed number is
easier to land than a released mouse button and it is what makes the acceptance row checkable.

**Insert from the workspace, and this is the page that teaches it.** The **Insert** dialog offers
the workspace and a version side by side, and the version reads like the safer pick. A workspace
reference names an element, so it follows the edit just made and a document copy re-points it; a
version reference names a document and a version, and a copy has no version of its own for that
reference to become, so the copy goes on showing the original's parts.
[`onshape`](../../../.claude/skills/onshape/SKILL.md) § *Insert from the workspace, and keep
every reference inside one document* is the rule. Tutorials 13 and 14 insert the same way and do
not re-teach it.

## The shots this tutorial needs by name

| Shot | Why a rule cannot produce it | Req |
| ---- | --- | --- |
| the insert dialog, with the document's parts listed | this is the first time a student sees one tab reach into another | |
| both parts in the assembly, before the drag | the buried head is what the drag is for, and a page that skips it reads as if Insert placed them well | |
| both parts in the assembly, posed | the honest picture of an unmated assembly | |
| the tab, renamed | before and after | |
| the tab bar, before and after the drag | the drag itself has no dialog | |
| the distance box, with the typed number in it | the box is the whole reason the height is sayable | |

## Built

**Document `stickbot-draft9p4`**
([`fe052e60`](https://cad.onshape.com/documents/fe052e606c96bb7cc5aaf59f)), version
**tutorial 3 - the assembly** (`0dd51c03d74ff36806ada896`). Its `stickbot` assembly holds
`torso <1>` and `head <1>` and no mate feature, with the head 90 mm up the z axis and nothing off
in x or y. `stickbot` is the first tab on the strip.

**The end-of-tutorial-3 numbers are measured in `stickbot-draft9p4-check`**
([`86f40935`](https://cad.onshape.com/documents/86f40935a709a0748cdbb199)), at its own version
**tutorial 3 - the assembly**, because that document holds nothing past this page. Its tree reads
`stickbot`, `Origin`, `torso <1>`, `head <1>`, `Loads (0)`, `Mate features (0)`, and its strip reads
`stickbot`, `body`, `head`, `robot sizes`. The torso measures 72 × 48 × 96 mm and the head
72 × 63 × 72 mm, so a head 90 mm up stands 6 mm clear of a torso whose top face is at z 48.

**The Insert panel holds its work in a transaction, and only the tick commits it.** Every row click
raises the panel's own `Inserted:` counter and puts a row in the tree, but the assembly is unchanged
until the green tick: the red cross rolls all of it back, and so does reloading the page, which
reopens the panel with the same count still pending. A run that read the assembly over REST between
clicks saw an empty assembly each time and was reading the truth.

**A click at the middle of the head's face selects the origin.** The assembly's origin is drawn as a
point at dead center and sits in front of the face there. A point cannot be dragged, so the head
does not move however far the mouse goes. The pick has to land off to one side.

**Letting go of the drag leaves a distance field with the keyboard.** It arrives holding the
free-hand number, `90.1 mm` in this run, and typing `90` and pressing Enter set the occurrence to
exactly 90 mm. Pressing **f** while that field is up types the letter into it and opens an
expression list rather than zooming to fit.

## Captured

**`instructions/stickbot-draft9p4/source/assembly.rst`**, written from the 22 frames in
`instructions/stickbot-draft9p4/source/images/assembly/`. Sphinx builds the page with no warning;
every frame on disk is used and every frame the page names is on disk.

**The carried page named two frames that were not there and left one on disk unused.**
`assembly.rename-03.png` and `version-01.png` were referenced and missing, and
`assembly.first_tab-01.png` was on disk with nothing pointing at it. The whole page was recaptured
by following it into `stickbot-draft9p4-check`, so all 22 frames are this draft's.

**The pose step grew a fourth frame.** The drag's distance box is a step a reader has to take, and
it needs its own picture: a medium frame of where the drag starts, a held mid-drag frame, the box
with `90` typed into it, and the result.

**The frames are full windows, where draft9p3's Insert panel frame was cropped to the panel.** The
tree behind the panel is what the counter is checked against, so the crop hid half of what the
paragraph beside it claims.

## What we do not know yet

**Nothing this page needed is still open.** A mid-drag frame is capturable in both places it is
wanted: `assembly.pose-02` holds the head part way up with the mouse button down, and
`assembly.first_tab-02` holds the tab part way along the strip. Parts have to be inserted one row at
a time, and the panel stays open between them, so the two-frame answer is the only one available and
it is the one the page gives.

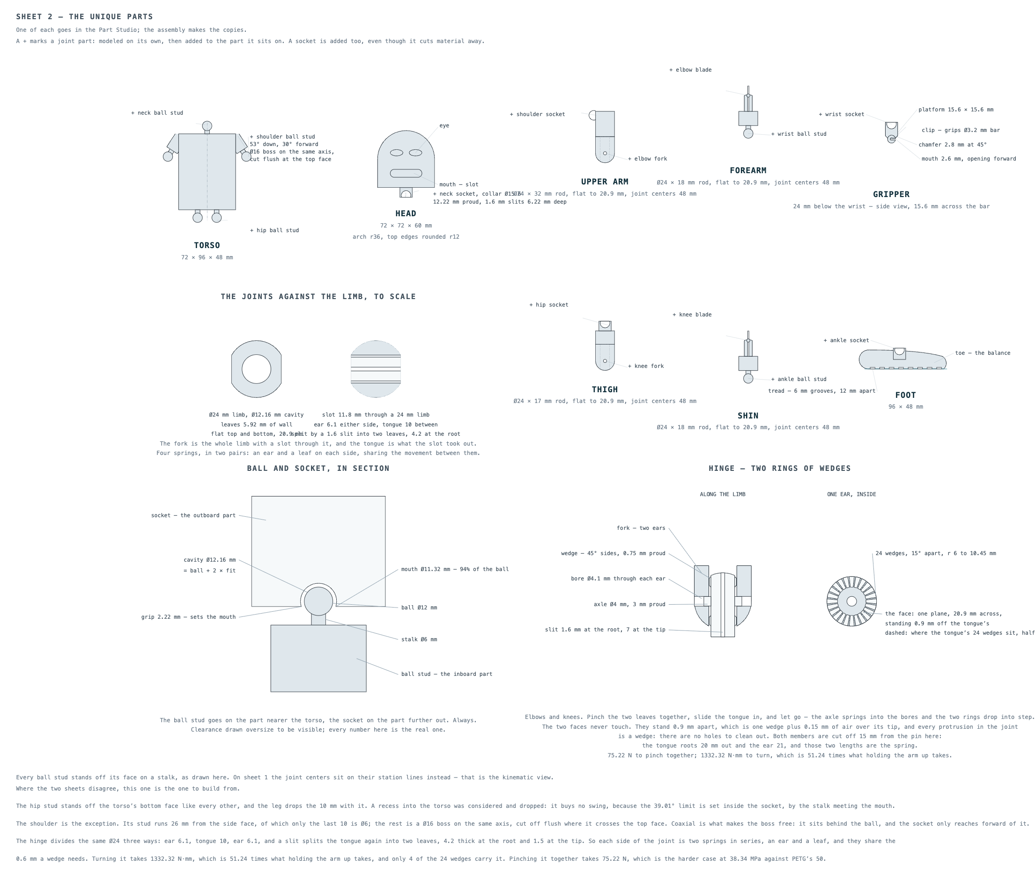
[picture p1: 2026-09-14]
instructions/robot-guide/source/images/plan-parts.png

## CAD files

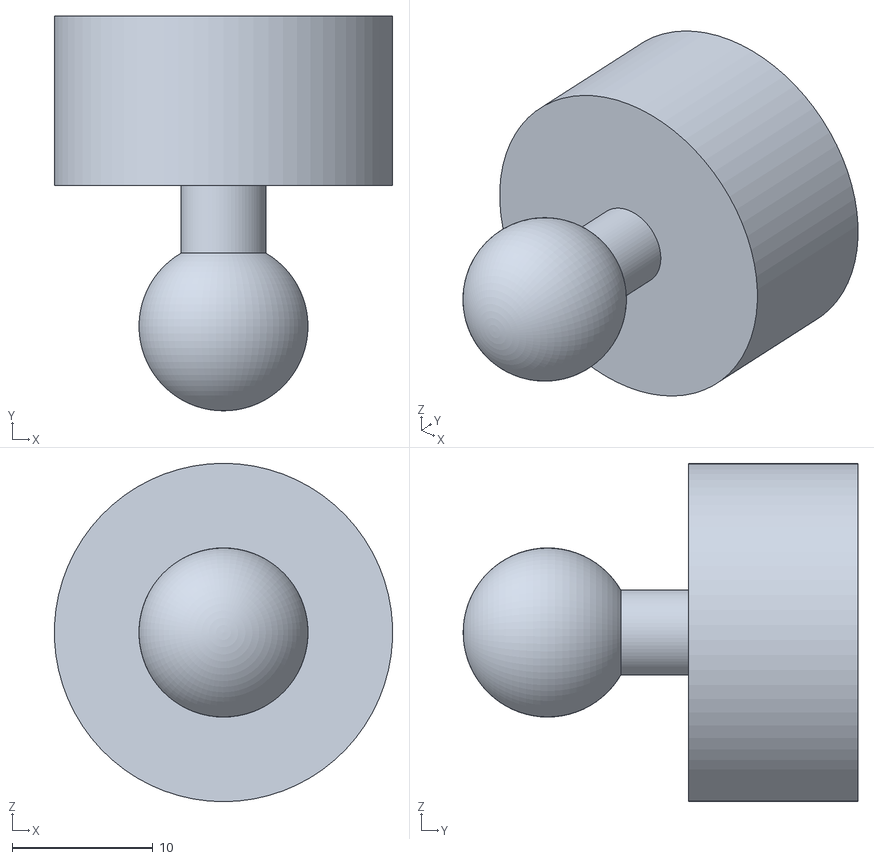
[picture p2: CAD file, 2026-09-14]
.docs/experiments/runs/2026-08-30-draft9p1p2/print/ball-stud.stl
24.0 x 28.0 x 24.0

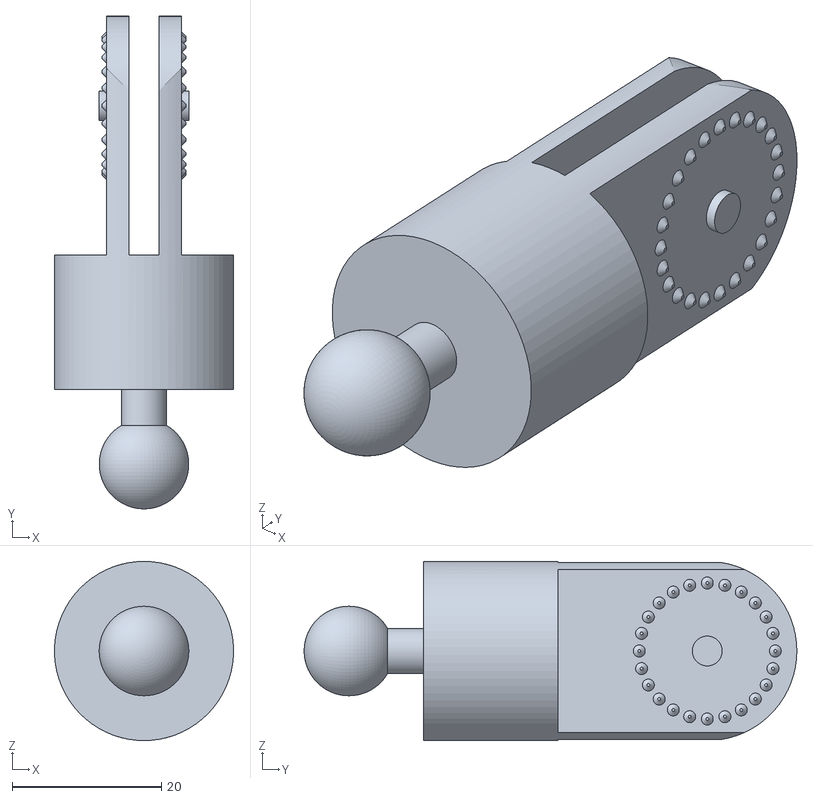
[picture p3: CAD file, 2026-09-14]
.docs/experiments/runs/2026-08-30-draft9p1p2/print/l-limb.stl
24.0 x 66.0 x 24.0

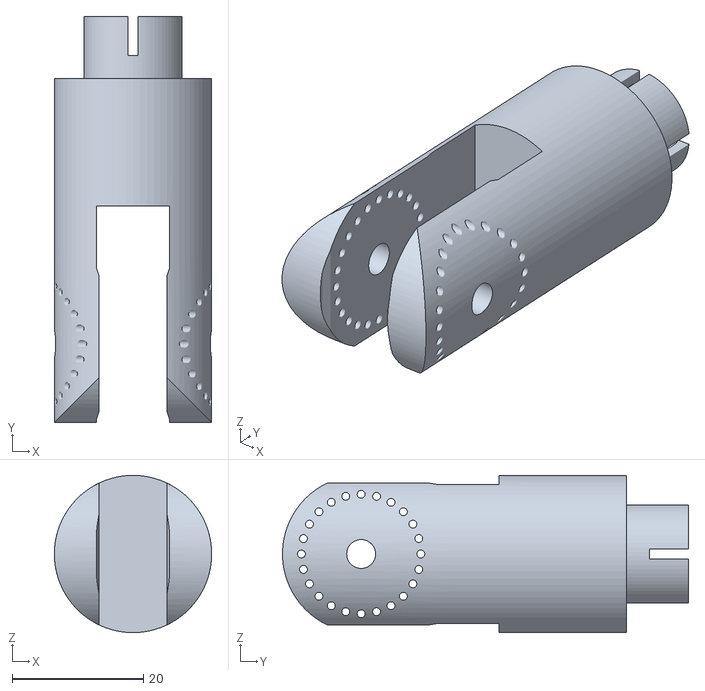
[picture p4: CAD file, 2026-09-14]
.docs/experiments/runs/2026-08-30-draft9p1p2/print/u-limb.stl
24.0 x 61.9 x 24.0

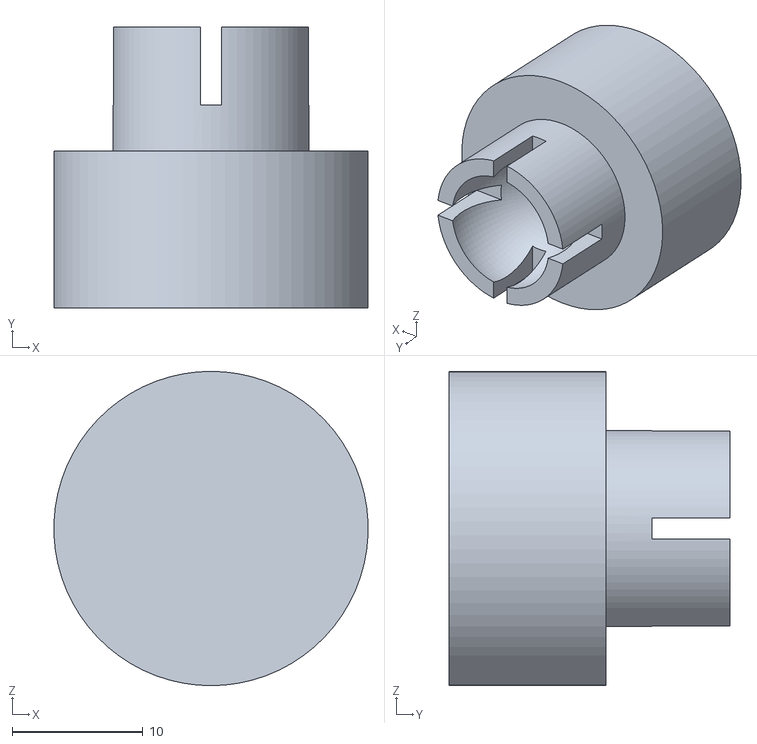
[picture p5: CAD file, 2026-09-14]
.docs/experiments/runs/2026-08-30-draft9p1p2/print/socket.stl
24.0 x 21.4 x 24.0

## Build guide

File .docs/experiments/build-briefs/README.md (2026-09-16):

# Build briefs — what every one of them asks for

A brief is **a specification, not a lesson.** Build the part in Onshape, find the click path
that works, and write down what actually happened. The lesson is written from your notes
afterwards. Where a brief's step does not work as written, that is the finding — record what
you did, what you expected, and what happened, then deviate as little as needed and label it.

Read [`../../onshape-gui-howto.md`](../../onshape-gui-howto.md) before driving the browser, and
[`../../../.parts/onshape.md`](../../../.parts/onshape.md) for the modeling standard.

## A convention shared by two parts lives here, and only here

If two parts have to agree about something, this file settles it and the briefs do not restate
it. A brief says what is true of **its own part**; anything that only means something when two
parts meet — an axis, a sign, a station, a fit, a naming rule — belongs in a section below.

The failure this prevents is not disagreement, it is **invisible** disagreement. A convention no
single brief owns gets decided independently by each brief, every decision looks correct inside
the brief that made it, and nothing is wrong until the parts are assembled. Run 5 hit this twice:
the head and the feet faced opposite ways because no file said which sign of Y was forward, and
the hip through ground stations were five millimeters out because this README carried a copy of a
table `make_plans.py` computes.

So, when you find yourself picking a value because the brief did not give you one:

- If the value only affects your part, pick it, mark it **proposed** in the numbers table, and say
  what you did with it.
- If any other part can see it, **stop and add it here**, then reference it from the brief. Do not
  copy it into the brief — a copy is the failure, not the fix.
- If a number is computed somewhere already, link to the file that computes it instead of writing
  the number down.

## Every part is built standalone

Each brief builds **one part in its own document**, not the shared Part Studio. The real robot
is one Part Studio hung off one layout sketch, with every part modeled in place at its own
station — see [`../../robot-build-plan.md`](../../robot-build-plan.md). That model is assembled
from proven click paths; these briefs are how a click path gets proven.

So: build at the origin, not at the part's station. Where a brief needs a station height it
says so and gives the number.

## Coordinates

Onshape is **Z-up**. Top = XY, Front = XZ, Right = YZ. "Vertical" is Z; "fore-and-aft" is Y.

**The robot faces −Y.** Its front is the side Onshape's own Front view looks at, so the front
elevation and the Front view are the same picture. Every part that has a front and a back — the
head's face, the foot's toe, the shoulder's forward lean — puts it on −Y. This sign is the kind of
thing each brief will otherwise decide for itself, and run 5 assembled a figure with its head and
its feet pointing opposite ways before anyone noticed.

The robot's origin is the **center of the torso**. Every station is computed in
`src/stickbot/make_plans.py`, which holds them at module level so anything measuring
the CAD can import them rather than copy the arithmetic. **Import them.** The table below is a
printout, not a source; where it disagrees with the file, the file is right.

```
python -c "import sys; sys.path.insert(0, 'instructions/robot-guide'); import make_plans as p;
           print(p.SOLE_Z, p.ANKLE_Z, p.KNEE_Z, p.HIP_Z, p.SH_Z, p.NECK_Z, p.HEAD_T, p.HEIGHT)"
```

| Station | z | Station | z |
| --- | -- | --- | -- |
| ground, `SOLE_Z` | −178 | shoulder ball, `SH_Z` | +19.235 |
| ankle, `ANKLE_Z` | −154 | neck, `NECK_Z` | +58 |
| knee, `KNEE_Z` | −106 | top of head, `HEAD_T` | +137.4 |
| hip, `HIP_Z` | −58 | whole figure, `HEIGHT` | 315.4 |

Right-hand limbs only: the shoulder ball at x = 49.551 and y = −7.824, legs at x = 24 (`LEG_X`).

These are the draft9p0 stations, at twice the size, and **nothing has been built to them yet.**
The figure is 315.4 rather than a doubled 316.3, because the joint kept its own numbers while
everything around it grew. The 1× stations that run 5 measured on an assembled figure are in this
file's history; do not read across from them.

## Every number says where it came from

Each brief's numbers table carries a **Source** column:

| Source | Means |
| --- | ----- |
| plan | [`../../robot-build-plan.md`](../../robot-build-plan.md) — a variable, or a station derived from one |
| built | measured on a model in a previous run |
| derived | arithmetic on the rows above it, and it moves when they move |
| proposed | **written for the brief and never checked.** A starting value. Say what you did with it |

A brief with no proposal in it is a brief nobody had to think about. A proposal presented as a
settled number is how a robot gets built to a figure somebody invented at a keyboard — which has
already happened once here, and is why this column exists.

## The drawings are part of the brief

Where a brief has a sheet in [`images/`](images/), read it before the numbers table. A table says
what the sizes are; a sheet says what the shape is, and every failure so far has been a shape
failure that passed its numbers — a socket built upside down, relief slits that did not cut
through, a fork drawn as a rectangle, a detent that cannot cam.

The sheets are generated by `src/stickbot/make_brief_sheets.py` from the same
constants as the student plan sheets. **Do not redraw a sheet by hand and do not edit the SVG** —
change the script and re-run it, or the sheets and the plan will disagree. Each sheet is written
as both `.svg` and `.png`; they are the same drawing.

`images/run2-*.png` are renders of what run 2 actually built. They are there to show you the
joint, and where a caption says so, to show you the defect being fixed. They are not the
specification.

## Every limb is a Ø24 cylinder

`#limbD` = `#torsoH / 4` = 24. **Settled 2026-08-11, and the joints are sized to fit inside the
limb — never the limb grown to fit a joint.** The hinge's fork is drawn as *full slices of the
Ø24 limb*, so its geometry is derived from that circle: the blade's full chord at ±5.0 is 21.817,
and its corners land **on** the Ø24 surface.

The nozzle sets the floor, not the sizes, and it does not scale with the robot — so at twice the
size the same wall is twice as many perimeters and the floor is further away than it was. The ear
is 6.4 because that is what makes it as strong as the tab it presses against, not because of any
number of passes. Where a dimension has a reason, the reason is in the part's own brief.

Do not invent a section for a limb. If a brief seems to want one, that brief is wrong — say so
rather than picking a number.

The build plan's Stage 5 lists four *teaching routes* for the limbs — sloppy quadrilateral,
ellipse, loft, filleted box — so that each limb teaches a different tool. **Those are tools, not
sections.** Where a route cannot produce a Ø24 cylinder, the route gives way, not the diameter.
Report it if you hit one.

## What every report must contain

Write `build-notes.md` — **not** `report.md`, which the Write tool refuses.

1. **Where the work is**, as the opening section: document name, document id, element id, a
   **published named version** with its id, the version link, and the workspace link labeled as
   live. Publish the version before you write. Say plainly whether you opened the links or only
   assembled them from ids.
2. **The click path that actually worked**, step by step, with real UI names, and the screenshot
   filename beside each step.
3. **Every acceptance measurement**, what you got against what was expected, and how you
   measured it.
4. **What did not work**: wrong assumptions in the brief, steps in the wrong order, anything
   that took more than two attempts.
5. **What the brief never said** that you had to work out for yourself.
6. **A retrospective**, answering three questions: what went well, what went poorly, and what
   would you change about the brief, the how-to, or the way you were briefed. Answer as
   yourself, about this run. This is a required deliverable, not a courtesy — you cannot be
   asked afterwards, because an agent that has finished cannot be reached.

## Screenshots are half the deliverable

**Drive the browser through
[`../../../src/stickbot/gui_steps.py`](../../../src/stickbot/gui_steps.py), not through bare
`page.mouse.click` calls.** Its `Steps` object takes each click with a sentence saying what you are
clicking, and writes the frame and both `steps.log` lines itself:

- `NN-a-select-<what>.png` — the moment something is **selected**, before you commit it. The
  selection must be visible: highlighted geometry, a filled dialog field.
- `NN-b-done-<what>.png` — the same step completed.
- `NN-x-<what>.png` — anything that surprised you.

`NN` is a counter that only goes up, so two frames never collide and the numbers are the order
things happened in. Run 5 keyed its screenshots by name instead, reused the names, and each frame
overwrote the last — that run has no click path recorded, only one reconstructed afterwards from
its scripts.

Zoom or crop where it helps. A screenshot in which the thing under discussion is 20 px wide
teaches nothing.

## Render every part on its own, and look at it

Before you write anything up, render each part **alone**, from at least three angles, using
`shadedviews` — [`../../onshape-gui-howto.md`](../../onshape-gui-howto.md), *Rendering the model,
and looking at it*. Say what you saw, and say if it does not match what the numbers implied.

This section exists because of two specific failures. A socket's relief slits were reported as
present and were, in the agent's own later words, "decorative". A hinge fork was invisible in
all four standard whole-model views because the parts overlapped along the camera axis, and
nobody noticed the joint had never been looked at.

## Measure, do not infer

Never claim a verification you did not perform: no menu name you did not see on screen, no
dimension you did not measure, no timing you did not clock. If you could not check something,
say you could not.

An acceptance check can pass on a wrong part. A relief slit came out 2.7 mm deep against 5.5
specified and every headline number still passed, because nothing measured the cut's z-extent.
Where a brief asks for an extent or a wall thickness, that is why.

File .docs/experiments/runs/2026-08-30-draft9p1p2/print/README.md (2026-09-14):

# The print files, and how to lay them on the bed

Four binary STLs, in millimeters, exported from `stickbot-draft9p1p2` at a chord tolerance
of 0.02 mm. Both limbs are watertight with zero open edges, and their bounding boxes match
the model; [`../check.py`](../check.py) is what proves the model.

| File | What it is | Bounding box |
| ---- | --- | --- |
| `u-limb.stl` | the thigh: a knee fork, a 19.5 mm rod, a hip socket | 24 × 62 × 24 |
| `l-limb.stl` | the shin: a knee blade, an 18 mm rod, an ankle ball stud | 24 × 66 × 24 |
| `socket.stl` | the socket alone, on a 12 mm stub | 24 × 21 × 24 |
| `ball-stud.stl` | the stud alone, on a 12 mm stub | 24 × 28 × 24 |

## Lay the limb axis flat, with the slit standing up

The hinge is a spring, and both halves of it bend the same way: the ear and the leaf are
cantilevers rooted 21 and 20 mm from the pin, and what they carry is tension running along
the limb's own axis. Layer adhesion is the weakest direction an FDM part has, so the limb
axis wants to lie in the layer plane rather than along the build direction. Print each limb
lying down.

Which way it lies then decides what happens to the 4 mm slit. Turn the part so the slit's
gap stands vertical — the pin axis across the bed, the chord axis up — and the slit is two
vertical walls with air between them, which needs nothing. Turn it the other way and the
slit becomes a 33 mm ceiling to bridge.

At that orientation the teeth are 45° cones growing sideways out of vertical walls, which is
the angle that supports itself, and the socket's four relief slits come out as two vertical
walls and two 1.6 mm bridges.

## What is not settled

- **The Ø24 rod lying down touches the bed on a line.** A brim holds it; whether the first
  layers need more than that has not been tried.
- **The socket's cavity is a Ø12.16 dome on its side.** It is small enough that the droop
  may not matter, and nobody has measured it.
- **The socket's finger is 1.42 mm at its thinnest**, at the cavity's equator, which is
  three and a half extrusion widths and the thinnest structural section in the robot.
- **Every force in the design assumes PETG**, E 2000 MPa and yield 50 MPa. Print it in
  something stiffer and the press force rises with E.

## What it should feel like

- **Pressing the knee together: about 5.2 kgf**, and the tongue goes in nose first, so the
  force builds toward the end rather than all at once.
- **Pressing the ball into its socket: about 5.2 kgf as well**, and it should snap over
  rather than crush in. The four fingers reach 59% of PETG's yield opening the mouth, so
  they are meant to spring back; if the mouth stays open afterward, the print came out
  narrower than drawn and that is worth measuring before printing another.
- **Turning it once together: 414 N·mm to break away**, which at a hand 150 mm from the pin
  is 0.28 kgf. That is 16 times what the limb needs to hold itself up.
- **It should click twenty-four times in a turn**, once every 15°.
- **Expect the hold to fall as the valley rims round off.** A 0.05 mm radius on the rim takes
  it to 82% of new, 0.10 mm to 65%, and 0.15 mm to 47%. The derivation is in
  [`.docs/reviews/hinge/`](../../../../reviews/hinge/source/index.rst).

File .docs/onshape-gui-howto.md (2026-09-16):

# Driving Onshape's GUI

Read this before driving the browser. It covers connecting and identifying your page, reading an
error, creating a document, selecting, tools and dialogs, sketching, measuring, rendering, and
read-only REST.

**Section 2 comes before the building sections on purpose.** Run 5 posted eleven broken mates
before finding out where Onshape keeps the message that said why, so how to read a failure is
here ahead of how to make one.

Assembled 2026-08-11 from run 1's reports in [`runs/2026-08-11-run1/`](runs/2026-08-11-run1/),
extended after run 2 from the three `build-notes.md` files under
[`build-log/`](build-log/), and after run 5 from
[`experiments/runs/2026-08-13-run5/`](experiments/runs/2026-08-13-run5/). Where something was seen
once rather than established, it says so.

**Where run 1 and run 2 disagree, both are recorded.** Onshape's dialog defaults are not stable
between sessions, and treating one run's observation as a rule is itself a way to lose an hour.

## The hard rules, before anything else

- **Port 9223 only. Never 9222** — that is the user's own browser.
- **Never close a page you did not create.** Never `bring_to_front()`. Never close the context
  or the browser — closing the context destroys the shared login for everyone.
- **Every Bash call under 90 s**, with an explicit timeout. Every Python script must terminate;
  wrap Playwright in `with sync_playwright() as p:` so it does.
- **GUI only for geometry. REST is read-only**, for verification.

## 0. Onshape is Z-up, and this changes every sketch

- **Top** = XY, normal **Z** · **Front** = XZ, normal **Y** · **Right** = YZ, normal **X**.
- "Vertical" is **Z**. "Fore-and-aft" — and so a hinge axis, and the direction of a Mirror about
  Front — is **Y**.

Getting this wrong puts every sketch on the wrong plane, and the model still builds.

## 1. Connect, and know which page is yours

**Run every script with `.venv/bin/python` from the repository root.** Plain `python` and
`python3` do not have Playwright. The environment is `uv`-managed, so `uv run python` works too;
`guide/.venv/bin/python` appears in older notes and no longer exists.

```python
from playwright.sync_api import sync_playwright
with sync_playwright() as p:
    b = p.chromium.connect_over_cdp("http://127.0.0.1:9223")
    ctx = b.contexts[0]
    page = ctx.new_page()          # this one is yours
```

**`onshape_session.CDP_URL` is 9223, the agent's browser, and 9222 is reached by naming it.**
9222 is the browser a person signed in to and is sitting in front of. Until draft9p1p6 the default
was 9222 and only `onshape_gui.connect()` moved it, so a script that imported `onshape_gui` landed
in the agent's browser and a script that imported only `onshape_session` did not; draft9p1p6 ran
its whole Phase C and Phase D through the person's browser before a capture of a sign-in screen
gave it away. **A default that reaches somebody else's session is the failure**, because nothing
in the answer says which browser served it.

**Identifying your page later is the trap.** There are six or more near-identical Onshape tabs
open. Matching on title or URL *will* find someone else's document — in run 1 this happened
twice, once to an agent and once to the session driving it, and both nearly typed into another
document's rename box.

The reliable pattern: **stamp your own page, once, immediately after creating it**, then find it
by that stamp and nothing else.

**A stamp is a convention, not a guarantee, so look before you stamp and fail on any count that
is not one.** In run 3 an agent found its assigned stamp already sitting on another agent's page;
a lookup returning the first match would have driven the whole build into someone else's
document. Copy a prompt, hard-code a default, or leave a page from an earlier run carrying the old
name, and the collision comes back with nothing to detect it. The assertion is what turns an
undetectable wrong-document write into a crash on line one — and **zero matches is a failure
too**, not a reason to fall back to the first page.

```python
MARK = 'MY_MARK_' + secrets.token_hex(3)   # your own suffix, reported in your notes

def marks(ctx):                            # read-only census; run it BEFORE you stamp
    out = []
    for pg in ctx.pages:
        try:
            out.append((pg, pg.evaluate("window.name")))
        except Exception:
            pass
    return out

assert not [p for p, n in marks(ctx) if n == MARK], "somebody already has my mark"
page.evaluate(f"window.name = {MARK!r}")
...
def mypage(ctx):
    hits = [p for p, n in marks(ctx) if n == MARK]
    if len(hits) != 1:
        raise SystemExit(f"expected exactly one page marked {MARK}, found {len(hits)}")
    return hits[0]
```

`window.name` survives a `page.reload()` only if you set it again afterwards — reloading clears
it. Set it again right after any reload.

**Telling a signed-out browser from every other fault.** `GET /api/users/sessioninfo` returning
**200 with a body carrying `roles`** is signed in; **204 with an empty body** is signed out, and
no agent can fix that. Anything else is a *different* fault and must not be reported as a
sign-out: **429** is rate limiting, back off; **5xx** is Onshape down, wait; a thrown error is the
CDP connection. Run 3 observed the 204 five times in one outage and the flip to 200 when a human
signed in — that is one day's observation, not a documented contract, so log the status you
actually got.

## 2. Finding out why something failed

Read this before you build anything. Onshape's failures are quiet by design: a feature that could
not be made sits in the tree in `ERROR` and the rest of the model regenerates around it.

**The message lives in a tooltip and nowhere else.** A failed feature's row carries
`ns-list-item-error` and a red icon. Hover the icon — at the row's left edge, x ≈ 54, not at the
name — and the text appears. Two wordings have been seen: `<name> has error: <message>`
(*"Mate cannot resolve mate connectors."*) and `<name> did not regenerate properly: <message>`
(*"Could not create all instances as entered."*). **A scrape that matches on
`error|fail|cannot|could not|unable` finds neither reliably; match on `regenerat|error` too.**
`GET .../features` gives you `featureStates`, which is a status and no message at all, so **a
failing feature cannot be diagnosed from REST**. Get the status from the API, then go to the
browser for the reason.

```python
pg.evaluate("""() => Array.from(document.querySelectorAll('.os-list-item'))
  .filter(e => e.className.includes('ns-list-item-error'))
  .map(e => e.innerText.trim())""")
```

**A 200 from the API means "accepted", not "worked".** Run 5 posted eleven mates that all returned
200 and all landed in `ERROR`, because Onshape rewrote a query type it did not like rather than
refusing it. What catches this is a volume or a bounding box, never a status.

**`featureStatus: OK` and a green tree are not evidence either.** A slit that cut half its length
into empty air, and an assembly translated 37 mm off the origin, both left every feature `OK`.
Measure the geometry.

### Failure modes, with the symptom you will actually see

| Symptom on screen | Cause | Fix |
| --- | ----- | --- |
| Click does nothing at all | a tool is still armed, usually Dimension | Escape once, then click |
| Typed dimension ignored, sketch still black | you pressed Escape instead of Enter | retype, commit with Enter |
| Region field empties when you pick the axis | focus never left the region field | click into the axis field first |
| *"Could not create all instances as entered"*, feature red, and every dimension still measures right | Mirror or Pattern transformed result faces instead of replaying the feature; only the original instance was cut | tick **Reapply features**; catch it with **volume**, since N instances of a cut must remove N × the single cut |
| *"Select a mirror plane"* after picking one | the tree scrolled; you hit the panel header | use the feature-tree filter box |
| *"Select Extrude direction."* on a feature you only meant to flip | the `Direction` checkbox is a custom-direction reference field, not a flip | untick it, use the arrow beside `Blind` |
| Two parts become one, or most of a body vanishes | merge scope left on *Merge with all* | set the scope by hand |
| A rod runs straight through another part, preview looks right | starting offset has **its own flip control**, separate from the main direction | check the bounding box |
| A cut is half as deep as asked, and every measurement still passes | Remove extrude arrived with `oppositeDirection` set, so one half of a two-sided depth went into empty air | measure the **z-extent of the cut face**, not the result of the cut |
| Whole sketch turns red, *"could not be solved"* | Coincident added over an existing implicit constraint | undo; redraw the line instead |
| Rename produces `Ball studPart 1` | Ctrl+A does not clear the rename box | End, then Backspace |
| Blank screen, no error | Hide applied to a multi-part selection | undo, deselect, hide one thing |
| Sketch region cannot be picked inside a solid | the dialog picks the solid instead | hide the parts, show the sketch |
| A click on the canvas selects nothing at all | picking follows the hover target | `mouse.move`, wait 400 ms, then click |
| A dimension does nothing — no box, no error | label placed too near the canvas bottom edge | move the label click inward |
| A circle comes out enormous (Ø226) | `Control+A` did not clear the numeric field | use `locator.fill()`, read it back |
| Extrude flip does not take | direction set before the entities were picked | set the flip last, verify by volume |
| Circle drawn in a new sketch is an ellipse | a new sketch does not auto-orient | press `n` after creating it, check the cube |
| Mate returns 200 and sits in `ERROR`, dialog named both connectors | wrong query `btType`; Onshape rewrote it on the way in | hover the row for the message, then repost with the type a GUI-built mate reads back as |
| The whole assembly moves and every mate stays green | a drag landed on empty space, and nothing is fixed by default | `Meta+Z`, then right-click the base part → **Fix** |

## 3. Create a document and set units

1. `page.goto("https://cad.onshape.com/documents")`, wait ~4.5 s.
2. **`button:has-text('Create')` matches a hidden "Create account" button first.** Use
   `button:has-text('Create'):visible`.
3. The **Create menu items are not in the DOM** in any form the ordinary selectors find — not
   `[role=menuitem]`, not `li`, not `a`. Click **Document…** by coordinate: take the Create
   button's `bounding_box()` and click at `(x + 30, y + height + 18)`.
4. In the **New document** dialog, scope everything to the dialog or you will hit the page's own
   Create button behind the modal:
   `page.locator("div[role='dialog']:visible").first` then
   `dlg.get_by_role("button", name="Create", exact=True)`.
5. Units: **☰** (left of the document name) → **Workspace units…** → *Length default unit* =
   **Millimeter**. Set **Display decimals** to **0.12345** — at the default `0.123` you cannot
   tell 4.996 from 4.9961, and several run 1 checks needed five places. Green ✓.

**The red ✗ discards the change silently and leaves you in inches.**

**Workspace units is the one dialog built from real `<select>` elements**, so `select_option(label=
"Millimeter")` works there and coordinate-clicking the list does not — the `<option>` never becomes
visible to Playwright. Feature dialogs are the opposite; theirs are custom widgets that only answer
to clicks. Read the value back (`4: millimeter`, `5: 5`) rather than trusting the click.

**The New document dialog remembers the folder you last created in**, so its location list opens
inside that folder and the folder's own row is not there to click. Look for the row before clicking
it, and treat its absence as *already there* rather than as a miss.

## 3b. Variable Studios — one set of variables for the whole document

**Onshape variables are scoped to a Part Studio.** Ten `Variable` features at the top of the ball
and socket's tree are invisible to every other tab. A **Variable Studio** is the document-level
element that fixes that, and it is on the same **+** menu as *Create Part Studio* and
*Create Assembly*, as **Create Variable Studio**.

**The + that opens that menu is not at a fixed place.** It sits at the left end of the tab
bar, and the tab bar begins where the open left panel ends. With *Versions and history*
open the + moves from x = 57 to x = 600, and a click at the remembered spot lands on bare
tab bar and opens nothing. Ask the page for the box of `.btn-add-element` rather than
remembering where it was, and shut the panel before framing the tab strip, because the
panel pushes the newest tab off the right of the usual clip.

The tab is a table with **Name**, **Variable type**, **Value** and **Description**, a
**Variable Studio name** box above it, an **Insert Variable Studio** button, and along the bottom
edge a control reading **Insert into all Part Studios and Assemblies**.

**All of the following was measured on 2026-08-20 in a scratch document, not read off the help.**

- **`#name` works exactly as it does for a local variable.** In a Part Studio that can see the
  studio, `#torsoH * 2` is accepted; a name that resolves nowhere — `#nosuchvar * 2` — is refused
  by the server outright, so an unresolvable name fails loudly rather than evaluating to zero.
- **A tab created *after* the box is ticked inherits the variables.** This is the one that decides
  where a Variable Studio goes in a build order: it can be made once, first, and every Part Studio
  made later can use it without doing anything.
- **A tab that existed *before* the studio did inherits them too.** Measured 2026-08-20 while
  building the robot's tutorial 1: the Part Studio a new document arrives with resolved `#torsoW`
  in a dimension field, and the Variable Studio was created after it. So the order is a
  convenience, not a requirement, and a student who starts sketching before making the studio is
  not stuck.
- **`Insert into all Part Studios and Assemblies` is a checkbox, not a one-shot action.** Its
  markup is `button.insert-into-all-button`, and it is on when the button holds an `svg.checked`;
  there is no `input[type=checkbox]` to read, so a script that looks for one always sees "off".
- **The first Variable Studio in a document arrives with the box on; a second arrives off.**
  Measured by deleting every Variable Studio in the document and making one from clean: it held an
  `svg.checked` before anything was clicked. Making a second one in the same document gave an
  unchecked button. Read the state rather than ticking it blind — a tick on an already-ticked box
  turns it off, and which state you find depends on what is already there.
- **A Value cell takes two double clicks from cold.** The cell is a `div.os-td` that sits over the
  input and intercepts the pointer. The first double click focuses the div; the second opens the
  `INPUT`. Loop until `document.activeElement.tagName` reads `INPUT` — three tries is enough — and
  only then type. A single double click leaves focus on the div and everything typed afterwards
  goes somewhere else: four values entered that way read back as `0 mm` with the last one landing
  in the next row's Name cell.
- **An empty placeholder Name cell is the exception: it takes a single click.** The row does not
  exist yet, so there is no cell over an input to fight.
- **Tab commits the row but does not reach the Value cell.** The name is accepted, the value
  defaults to `0 mm`, and a fresh empty row appears below. Click the Value cell yourself.
- **Right-click a variable row → Delete** removes it.
- **Inserting a Variable Studio adds no feature to the feature list**, and
  `GET /api/variables/d/{did}/w/{wid}/e/{eid}/variables` reports only *local* variable tables, so
  it comes back empty for a tab that can nonetheless resolve the names. Neither is evidence that
  the insert failed. **To test whether a name resolves, post a feature that uses it** and see
  whether the server accepts it.
- **A new document is in inches.** Typing `48 mm` into a Value cell is accepted and stored, and
  the cell then reads `1.89 in`. Set the workspace units first — see §3 — or every value in the
  table is displayed in the wrong unit while being right underneath.

- **`POST /api/variables/d/{did}/w/{wid}/e/{eid}/variables` takes the array, not the table.**
  The GET returns `[{variableStudioReference, variables}]`; posting that object back is a 400
  (`Cannot deserialize ... ArrayList<BTVariableParams> from Object value`). Post the inner
  `variables` list. The failure is loud, but a script that ignores the status reads the variables
  back unchanged and looks like a model that does not follow its dimensions.

Onshape's own guidance is to leave the box **off** and insert the studio by hand where it is
wanted, because a variable change otherwise regenerates every tab in the document and makes a
merge hard to read. That advice is written for large documents; this robot has ten tabs.

## 4. Selecting things

**Onshape's DOM defeats ordinary selectors.** Assume you will be clicking coordinates, and build
the habit of finding them from something measurable rather than guessing.

- `page.locator("input:visible")` and `bounding_box()` are reliable and are usually the anchor
  you want — find a known input, then offset from it.
- `page.locator("text=Some Label")` works for feature-tree entries and part names, but it is a
  **substring** match and takes the first node. A studio named the way this project names things
  — `Stub circle` sitting directly above `Stub` — hands you the sketch when you asked for the
  extrude. Use `text="Stub"` for an exact match.
- **The feature tree scrolls, and a row outside the panel is unclickable** — silently, with no
  error. Rows can end up above the filter bar or below the panel once the tree gets long. Scroll
  the tree, then assert the row's y is inside the panel before clicking.
- Toolbar buttons, menu items, and most dialog controls do **not** resolve. Screenshot, read the
  position off the image, click with `page.mouse.click(x, y)`.
- **A bare `mouse.click` on the canvas selects nothing.** Onshape's picking follows the *hover*
  target, so you must `mouse.move(x, y)`, wait ~400 ms, then click. This cost run 2's hinge agent
  its first hour.
- **Take a screenshot after every coordinate click** and confirm the state changed. A coordinate
  click that misses does nothing and reports nothing.
- **Everything a part puts on its own axis lines up when the camera is on that axis, and the
  nearest one takes the pick.** The head's socket is the case: on the bottom view the pick pixel
  meets the cavity sphere at (0, 0, -51.08) mm, 0.00 mm from all four traces of the cross slit and
  directly behind a mate connector that came in with the derived socket. Eleven rebuilds across
  nine pixels and three zoom levels could not get off it. Turn the camera off the axis first —
  `shift+7`, then arrow keys 15° at a time — and the same pick lands 2.76 mm clear of the nearest
  edge, on the face and nothing else. Check the angle rather than trusting it: project the point
  you want, read where the ray meets the shape, and refuse the pick when it comes out too close to
  something else.
- **Shift locks the reference to the face already hovered, so the order is the technique.** Hover
  the face until its inferred points come up, *then* press and hold Shift, then travel to the
  point you want, then click. Onshape keeps that face's points alive the whole way, even once the
  cursor has left the face. Pressing Shift first locks nothing: a spike did that four times and
  concluded Shift was inert, which was wrong. The frames say it plainly — without Shift every
  inference square is gone by the time the cursor reaches the target, and with it they are all
  still drawn. Reach for it whenever the reference jumps between a cylindrical face and the
  circular edge across it, which is most of the awkward mate connectors.
- **A lock on a face still cannot win a pixel another body owns.** A mate connector already on the
  model is a body, and a click on its marker selects the marker whatever is locked. If the point
  you want is drawn at the same pixel as somebody else's marker, move the camera; no modifier
  will separate them.
- **Clicking something already selected deselects it**, and a selection survives zooming and
  reframing. So a click that lands perfectly can leave the screen with nothing highlighted, which
  is exactly what a miss looks like. Click empty space to clear before any click you intend to
  check.
- **A click on empty canvas does not clear a selection made in the feature tree.** The rule above
  holds for geometry; a plane picked by its row stays picked through a canvas click, so a helper
  that cleared and then clicked the row turned the row off on every pass and reported that nothing
  was selected. Read the selection first and click the row only while it is not the one thing
  selected:

  ```python
  SELECTED = """() => Array.from(document.querySelectorAll('.os-list-item-name'))
      .filter(e => e.closest('.os-list-item').className.includes('selected'))
      .map(e => (e.innerText || '').trim())"""
  ```

- **Dragging an instance in an assembly needs a slow pointer and a clear place to start.** A
  mouse down, one move and a mouse up left the head exactly where it was, twice. It moved when
  the drag started on plain surface off to one side of the face, away from the origin marker, and
  walked up the screen in four moves with half a second on each. Read the result back:
  `GET /api/assemblies/d/…/w/…/e/…` returns `rootAssembly.occurrences`, and each occurrence's
  transform is a 16-number matrix whose 4th, 8th and 12th entries are where that instance sits, in
  meters.
- **Mirror copies; Symmetric constrains.** Two entities held either side of a line come from the
  *Symmetric* constraint, which is what a feature's constraint list calls `MIRROR`. The tool named
  *Mirror* draws a second copy of everything it is given, so handing it a shape's two sides leaves
  six entities where the reference has four. Armed, Mirror says *Select a mirror line* and takes
  the first click as that line; Symmetric reads a plain selection of the two entities and the line,
  and a shift click holds a sketch entity and one of the origin's axes together.
- **A circle's center loses the pick to the circle when the two are close in pixels.** Dimension
  handed a small circle measures to its near edge, which is a radius short, and says nothing. The
  center wins once the rim is a few tens of pixels away, so draw a circle several times the size it
  ends up, dimension from its center, and set the size last. The status strip at the bottom right
  of the window reads `Point: X … Y … Z …` when a point is what got picked.
- **A dimension's own leader is pickable too, and it runs through the geometry it measures.** A
  distance from an axis to a circle's center draws a line from that center straight out to its
  label, so a pick aimed at the circle's edge along that direction takes the dimension and
  Dimension then opens nothing. Aim at a diagonal instead.
- **A pick on the origin's axis has three answers once geometry is held there.** A circle's center
  constrained above the origin sits on the vertical axis, and a click there can take the center
  point, the circle, or the axis. Dimension took the axis and refused with *A dimension cannot be
  created between these items*, because two axes at right angles have no distance between them. Set
  a distance while the geometry is still off to one side, and constrain it onto the axis after.
- **A dimension moves whatever is still free.** Setting the size of a circle that is held only
  sideways slides it along the direction it is free in, so a pick worked out from where it was
  drawn lands on nothing. Place a thing before sizing it, and the pick after is at a place that can
  be worked out.
- **A constraint's own marker is pickable, and it sits next to the thing it marks.** The origin's
  vertical axis was aimed at a few millimeters below the tail of a shape, and the click took the
  tail, whose horizontal marker is drawn just below it. Mirror accepted the tail as its line
  without complaint. Aim at a stretch of the axis with nothing else near it, and confirm the shape
  came out where it should rather than that a pick selected something.
- **`n` gives the far side of the plane first.** Normal to has two answers and Onshape picks the
  one nearer the camera it already had, so the same key from two different views faces two
  different ways. Everything still picks, because the projection knows where the camera is, but
  the part is a mirror of itself on screen and the sketch's name in the corner reads backwards.
  Press `n` again to turn round, and decide which way you are facing by projecting 1 mm and -1 mm
  along the plane's own x: if the first lands left of the second you are behind the plane.
- **The bottom of the window is not canvas.** The status strip is at y = 966 and the tab strip at
  y = 983, so a pixel worked out from the camera can land on another tab and take the page with
  it. Check a computed pixel is inside the graphics area before clicking it.
- **The middle of a face is where the origin is drawn.** A click on the projected origin, meaning
  to take the head's bottom face, took the origin point instead. Chamfer accepted the point and
  changed nothing: twelve faces before, twelve after, no error anywhere and a feature in the tree.
  Pick a face off to one side, on plain surface, and read back what the dialog is holding. The
  field says `Face of head body` when the pick landed and stays empty when it did not.

**Read the camera; do not calibrate against it.** Onshape draws the Part Studio with WebGL on the
page's main thread, so a wrapper around `drawElements` and `drawArrays` on
`WebGLRenderingContext.prototype` can read the current program's `uMVMatrix` and `uPMatrix`
uniforms and hand you the camera itself, in meters. Enumerate `ACTIVE_UNIFORMS`, keep the
`FLOAT_MAT4` ones, and read their values with `gl.getUniform(program, loc)` — a map keyed on
`getUniformLocation` identity does not match what `uniformMatrix4fv` is called with.

- **Every frame draws several cameras.** Record `gl.getParameter(gl.VIEWPORT)` alongside each pair
  of matrices and keep the full-viewport draws: the view cube renders into 11×11. Screen-space
  overlays are full-viewport too, at about 0.001 px per mm, so take the survivor with the largest
  `uPMatrix[0]`.
- **The scale is one multiplication.** `px_per_meter = uPMatrix[0] * viewport_w / 2`, and
  `uPMatrix[5] * viewport_h / 2` agrees with it.
- **A model point becomes a pixel** through `uPMatrix * uMVMatrix`, column-major and orthographic:
  eye, then clip, then divide, then map NDC into the viewport and add the canvas origin with y
  flipped. A sketch (x, y) on the Front plane is the world point (x, 0, y).
- **Zoom to fit centers what is drawn, not the origin.** A shape running from -20 mm to 12 mm
  leaves the origin 4 mm above the middle of the window, and the same offset in millimeters lands
  on a different pixel every time the drawing grows. Work a pick out from where a known piece of
  the shape actually landed rather than from a distance that was clear on the last pass.
- **Matrices only refresh while the page draws.** Nudge the mouse a few pixels and wait before
  reading, or you get the frame before the one you are looking at.

**Assert the projection landed on ink** the first time you use it in a session: screenshot, and
check that the pixel you computed for a known point is inside a run of sketch blue on that row.
At zoom to fit on a Ø20 circle the origin projected to (923.0, 523.0) at 42.5714 px per mm, and
clicking the projected top of the circle selected that circle. Without the hook, the fallback is
to draw a circle roughly and dimension it: the value Onshape pre-fills into the dimension box is
an exact mm-per-pixel reading, and the circle's center gives you the origin's screen position.
The hook, the projection and the two camera laws in section 9 were measured in
[`experiments/runs/2026-08-18-spike-camera/findings.md`](experiments/runs/2026-08-18-spike-camera/findings.md).

## 5. Reaching a named tool

The toolbar's last slot is a **most-recently-used** button, so its meaning changes under you.
Two reliable routes:

- **Search tools** box at the top right (`alt/⌥ c`). Click it, type the tool name, and press
  **Enter** to take the first hit. Clicking the highlighted row in the flyout that appears
  beside it is *not* the same thing and in one run it closed the panel without opening the tool.
- The feature-tree **filter box** (`Filter by name or type`, top left) is the reliable way to
  reach a named plane or feature when the tree has scrolled. Type `Front`, click it, clear the
  filter afterwards.
- **Hover a button and read its tooltip; do not trust a remembered x.** Every toolbar coordinate
  written down in this file is a measurement of one window in one panel state, and the two ways it
  goes wrong both look like the tool is missing. Some of the numbers are left edges rather than
  centers: draft9p2 hovered *Fillet* at the recorded 396 and got no tooltip, because the button's
  box is 395 to 427 and its center is 411, and the recorded *Chamfer* 452 and *Mirror* 724 were
  likewise 11 and 17 px off their centers of 463 and 741. The other way is the panel: at 1600 px
  wide with nothing open down the side the Part Studio toolbar shows 29 buttons flat, and opening
  the versions panel both pushes them right and narrows the strip until it folds them into 16
  dropdown groups, so the tool you want is no longer a button at all. Dump
  `.tool.is-activatable` boxes with `y < 90`, hover each center, and take whichever one answers to
  the tooltip you asked for. It costs one pass over the toolbar and cannot go stale.

**Direction and axis fields take different things, and the two pattern kinds differ.**

- **Linear pattern's `Direction` accepts a plane, a face or an edge.** Its `directionOne` filter
  takes `LINE`, `CIRCLE`, `ARC`, `CYLINDER`, `CONE`, `REVOLVED` and `PLANE`. A default plane
  contributes its normal, a cylindrical face its axis, a straight edge its own direction. **Read
  the field back after clicking**: it names what it took — `Right plane`, `Face of Top edge
  fillet`, `Edge of Top edge fillet`. If it stays empty, the click missed the field, not the
  geometry. Run 3's foot put all three in, in turn, and read the field back each time.
- **Circular pattern's axis refuses a default plane, and refuses it silently** — the field stays
  empty, no error, no message, no color. Give it a **cylindrical face** or a **circular edge**;
  the edge is the way in when the face you wanted belongs to a part you have had to hide. Also
  switch the type from **Part pattern** to **Feature pattern** first.

**A feature pattern of a Remove or Add across a curved or filleted boundary needs `Reapply
features`.** Without it Onshape transforms the *result faces* of the original feature; where the
host surface differs at each station the transformed faces have nothing valid to land on, and the
feature errors with *"Could not create all instances as entered. Try selecting 'Reapply features'
option."* Ticking it replays the feature instead, which works. Run 3 hit this on the foot's sole
ribs and the hand's relief slits.

**`Equal spacing` is on by default, so a circular pattern's `angle` is the total sweep, not the
step between instances.** Run 3 entered 24 instances at 15° meaning 15° apart and got 24
instances crammed into 15°. It regenerated cleanly and looked plausible in the tree; only a
volume delta exposed it.

**The pattern split-button's `command-id` changes under you.** It is `linearPattern` until you
use a circular pattern, after which the same button is `circularPattern`. A script that hard-codes
either one breaks on the second use.

**Boolean → Subtract** also carries a **Reapply fillet** checkbox that the help page does not
mention.

**Flyouts close between script invocations.** Open the flyout and click the item inside the same
Playwright call, or it will not be there.

**The toolbar reflows when you leave sketch mode**, so x-coordinates probed inside a sketch open a
different tool outside one. Clicking where Extrude had been opened Sketch twice in a row, each
time leaving a stray `Sketch 1` to cancel. Use `gui.search_tool` rather than a remembered
coordinate whenever the mode has changed.

**`gui.search_tool` clears whatever was selected on the canvas.** Typing into the search box takes
focus away from the graphics area and the pre-selection goes with it, so a feature opened that way
arrives with an empty field and the tree shows an error. **Open the feature first, then pick** —
the reverse of the habit that works from the toolbar.

**The rectangle split-button's `command-id` changes under you**, exactly like the pattern
split-button above. It is `RECTANGLE_TWO_CORNERS` until you use the center point variant, after
which the same button is `RECTANGLE_CENTER` and a locator naming either one hangs for its full
timeout. Match any `command-id` containing `RECTANGLE`.

## 6. Dialogs

- **Name the feature before you fill the dialog in.** The dialog's title is editable — click it
  and type — for every feature type. It is the function-name discipline: naming it first forces the
  decision about what the feature is for, and a feature you cannot name yet is one you have not
  thought through. It also settles the frames. The tree row and the dialog header both sit inside a
  screenshot, so a name typed after the green ✓ is wrong in every picture of that step, and no
  reshoot can reach it. Renaming from the tree afterwards is the fallback, and it carries the
  `End`-then-`Backspace` trap in § *Failure modes*.
- **Fields do not hand focus on.** After picking into one list, clicking the next thing adds it
  to the *same* list. **Click into the next field first**, every time. This bit run 1 on Revolve
  (axis), Boolean (Targets) and Circular pattern (axis). In a **feature** pattern or mirror the
  list takes *the feature that made the geometry you clicked*: run 6 clicked a pocket's rim edge
  to fill the axis and got `Extrude 7` in `Features to pattern`, with the axis still empty.
- **A required field that is empty shows outlined red.** That is your check that a pick landed.
- **Not every refusal turns anything red.** A field can decline a pick by doing nothing at all —
  no error, no message, no color — and circular pattern's axis is the case that bit runs 2 and 3.
  **Check the field's contents, not the dialog's appearance.**
- **Checkboxes are not `input[type=checkbox]`**, so no `is_checked()` will tell you the truth —
  crop a screenshot of the row and look at it. Worse, **clicking to the left of the label focuses
  the control without ticking it**, and a focused checkbox looks enough like a ticked one to fool
  a screenshot taken from too far away. Click the label itself.
- **The green ✓ often needs two clicks** after typing in a numeric field: the first commits the
  field, the second accepts the feature.
- **Inside a dialog, Enter accepts the whole feature.** Use Tab between fields.
- **Do not trust any remembered default.** Run 1 saw Extrude open on **Add** with merge scope
  pre-filled; run 2 saw the same dialog open on **New** with *Merge with all* **unchecked** and the
  scope empty and red. Both happened with a solid already in the studio. **Look at which of New /
  Add / Remove / Intersect is underlined, every time**, and set the merge scope by hand every time.
  The failure mode differs — a silent weld, or a blocked feature — the discipline does not.
- **An empty merge scope is accepted, and does nothing at all.** Not a weld, not an error: the
  feature builds, the preview looks right, and the volume is unchanged. Run 3 lost an Intersect
  and a Remove that way in one build. Assert the field's text contains the part name before
  accepting.
- **Onshape will accept a feature with a required selection field left empty and park it in
  ERROR**, rather than blocking OK. Check `featureStates` through `GET .../features` after
  anything that took an unusual number of clicks.
- **Wheel-scrolling the feature tree drops focus from the dialog's open selection field.** The
  field stays outlined red, the tree row you then click merely highlights, and nothing lands.
  Run 6 committed a Mirror with no mirror plane this way; the model was unchanged and the red
  feature name was the only sign. Scroll first, then click into the field, then pick.
- **"…did not regenerate properly: Overlapping fillets." on a small boss means you picked the
  side wall, not the crown.** A Ø0.8 boss 0.6 tall takes a degenerate r0.4 crown fillet without
  complaint, but its barrel's two rims are 0.6 apart and any radius over 0.3 overruns them. The
  giveaway is that a *smaller* radius fails too. At 46 px/mm the crown ellipse and the barrel are
  one blob; zoom to about 110 px/mm before picking.
- **Set an extrude's direction flip LAST.** Setting `oppositeDirection` on an empty dialog and then
  filling in the entities loses the flip, silently. And prove it afterwards with a volume: a cut
  that removes nothing and a boss that merges into solid both look entirely normal in preview.
- **The extrude dialog carries the flip over from the previous extrude**, so it is not reliably
  off when the dialog opens and "click it once" is not a rule you can apply blind. Reading the
  feature's stored `oppositeDirection` back through `GET .../features` is the only way found so
  far to tell *the button did nothing* from *the direction was already right*.
- **The extrude's `Direction` checkbox is not the flip.** It opens an empty custom-direction
  reference field, and ticking it with nothing selected fails the feature with *Select Extrude
  direction.* The flip is the small arrow to the right of the `Blind` dropdown, tooltip *Opposite
  direction*. Hover a control before believing its label.
- **A starting offset has its own flip arrow, on its own row.** It is on the Depth row, not the
  Blind row, and flipping the extrude does not flip it. Run 3 found this building a stub whose top
  face had to land at z = −4.15.
- **Both arrows are `use` elements of `#svg-icon-flip-direction-opposite`.** Neither carries an
  aria-label, so a search by label finds nothing, and the `button.parameter-state-toggle` that sits
  on the depth row is not a flip at all: it is the precision toggle, and clicking it changes how
  the number is rounded. Ask the dialog for its `use` elements and keep the ones whose `href` holds
  `flip-direction`; sorted down the dialog, the first is the extrude's and the second is the
  starting offset's.
- **The starting offset does not follow the extrude's flip, and the two answer different
  questions.** The offset's arrow says which side of the sketch plane the cut *starts* on and the
  extrude's says which way it then *runs*. Building draft9p2's mouth all four ways on a head
  60 mm deep, with a 30 mm offset and a 3 mm depth, gave: neither lit, starts at −30 and runs to
  −33, outside; offset lit, starts at +30 and runs to +27, a groove in the back; extrude lit,
  starts at −30 and runs to −27, the groove in the face; both lit, starts at +30 and runs to +33,
  outside. **Onshape accepted the two that removed nothing** with no banner and no warning, so a
  Remove extrude proves nothing by being accepted.
- **Find out which arrows are lit by building one and reading it back, not by looking.** The
  arrows carry no state in the DOM and their drawn pixels change on hover, so a screen comparison
  says a click landed when it did not. Six openings of the same dialog in draft9p2 all started at
  *extrude flipped, offset not flipped* — every one of the four builds above lands exactly where
  that starting point plus the clicks made predicts — but that is one document and one session,
  and the way to know is to accept a throwaway with no clicks at all and read its parameters.
- **On a two-sided extrude the flip turns both ends the same way**, which is never what you want.
  *Second end position* draws opposite the first, so the two arrows oppose; clicking *Opposite
  direction* points them both the same way and the feature fails with *Failed to extrude
  selections, check input.* **To move an asymmetric two-sided cut, swap the two depths** and leave
  the flip alone. Run 6 cut a 5.5 mm slit 1.35 down and 4.15 up when it needed 4.15 down and 1.35
  up, and the flip made it worse before the swap fixed it.
- **Escape while a feature dialog is open discards the feature.** Not the selection, not the field
  — the whole feature, gone from the tree with no prompt. Run 6 sent one Escape believing an
  extrude had already committed and the Features count went 8 to 7. **Prove the dialog closed
  before you touch the keyboard**: check that a label unique to it, such as *Second end position*,
  is no longer on the page.
- **The right-click menu is cut short while a feature dialog is open** — a part offers only *Hide
  other parts* and *Zoom to selection*, with no Rename. Commit first, then rename.
- **`Control+A` does not clear a numeric field.** Typing `2` into a box reading `226.50977 mm` gave
  a Ø226.5 circle that merged a 226 mm disc into the part. Use Playwright's `locator.fill()`, and
  **read the value back before pressing Enter**.
- **`End` + Backspace is not reliable in the rename box either** — send Deletes as well.
- **Rename vanishes from the context menu whenever more than one thing is selected**, and Onshape
  leaves things selected constantly.
- **Double-clicking a feature row does not open its name for editing — it opens the feature.** The
  keystrokes that follow go to the graphics area as shortcuts. Run 6's spike typed a new name at a
  `Mate connector` row and got hidden planes, a zoom-window prompt, and *"Mate connector 1 did not
  regenerate properly: Cannot resolve entities."* on a connector that had committed clean a moment
  before. One **Undo** put it back. Before typing anywhere, read `document.activeElement` back and
  confirm it is the field you meant.

- **The dialog's name box is opened by a pencil, not by the title.** Clicking or double-clicking
  the title text gives a tooltip and nothing else. Hover the title, and a
  `div.os-dialog-button-edit-name` appears to its right; clicking that summons
  `input.os-dialog-header-rename-textbox`. `gui.name_feature` does exactly this.
- **The name box keeps the keyboard until Enter is pressed.** Typing the name is not the end of
  naming. A `n` pressed next to look normal to the sketch plane made a sketch called
  `pedestal outlinen`, and an `Alt+c` to reach Search tools was swallowed so that `Circle` went
  into the name and no tool ever armed. Enter commits the name and hands the keyboard back to the
  body; the input itself stays in the page afterwards, so `document.activeElement` is what says
  whether the box has let go, and counting the input always answers yes. `gui.name_feature` now
  presses Enter and reads the focus back, and `gui.search_tool` refuses to type while the name box
  holds the keyboard.
- **What a REST route reads is the last accepted state, not the dialog's preview.**
  `boundingboxes` gave the same box with an extrude previewed one way, the same box with it
  previewed the other, and the true box only after the tick. The dialog does write to the model as
  it is filled in, so the screen changes; a script that wants to know which way an extrude is
  running has to accept it and read afterwards.
- **A starting offset is measured to the far end of the cut.** A Remove of depth `#face`, 3 mm,
  with the starting offset set to 27, took the plastic between 24 and 27 mm from the sketch
  plane, not between 27 and 30. The head was left with a sealed cavity behind an unbroken face
  and one plane more than the part is supposed to have. Set the offset to where the cut is to
  come out, 30 here, and count the faces afterwards.
- **An extrude off the Front plane runs toward the front.** Measured on the head's eye: an Add
  extrude of a region on the Front plane, depth `#headD / 2 + #face`, with no direction click, put
  the new material between y = -33 and y = -30, which is the face a Front view looks at. The arrow
  beside `Blind` is what turns it around.
- **A dialog's mode can be a dropdown wearing the current mode's name.** Mirror opens reading
  `Part mirror`, and `Feature mirror` is not a button beside it. Clicking the words `Part mirror`
  opens the menu the other two modes are on.
- **The name box keeps the keyboard until Enter is pressed**, and everything typed after it lands
  in the title. Naming a sketch first and then pressing **n** for a normal view produced a sketch
  called `torso outlinen` on a view that never turned, and the tool name typed into Search tools
  went the same way, leaving `torso outlinenCenter point rectangle` and no rectangle. Press Enter
  and read the title back before touching anything else. A dialog whose fields are filled by
  clicking never showed this, because the click moves the focus.
- **Mirror opens on *Part mirror*, which mirrors the whole solid.** The type dropdown sits at the
  top of the dialog and holds *Part mirror*, *Feature mirror*, *Face mirror* in that order.
  Feature mirror is the one that copies a feature to the other side of a plane, and it wants the
  feature picked in the tree.
- **Where the Extrude dialog's flip arrows sit depends on which operation is chosen.** The arrows
  carry no state a script can read, so which of them is already lit has to be read by building a
  throwaway and looking at where the material went. Build that throwaway on the same operation the
  real feature uses. A `New` throwaway was read, and its two arrow positions were then clicked in a
  `Remove` dialog, where one of them is not an arrow: the slot came out 2 mm above the sole it was
  meant to cut into, and the pattern repeated that eight times.
- **Extrude arrives on `Add` once the studio holds a solid,** not on `New`. Read the row of words
  along the top before you accept: `New`, `Add`, `Remove`, `Intersect`. The frames of `Add` being
  hovered and `Add` being active look nearly identical — the active one is underlined.
- **A feature pattern and a feature mirror each carry a *Reapply features* tick, and it starts
  off.** It is the last checkbox but one, under *Second direction* and above *Skip instances*, and
  it is what the feature record calls `fullFeaturePattern`. Ticked, the copy is made by running the
  feature again at the new place; unticked, the faces the feature left are copied instead. The two
  put the same shape on the screen, so nothing but the feature's own record says which was used:
  the head's `second eye` came out unticked against a reference that is ticked, and every eye was
  still exactly where it belonged.
- **The default planes stay pickable in the tree after they are hidden,** which is how a hidden
  Right plane gets chosen as a mirror plane. Selecting one tints the whole graphics background
  orange; that is the selection, not an error, and it clears when the feature commits.

## 7. Sketching

- Select the plane in the Features list, then click **Sketch**. **A new sketch does not
  auto-orient** — `browser-access.md` says it does; it does not. Sketch 1 opened isometric and a
  circle drawn in it came out an ellipse. Press **n** after *creating* a sketch, not only after
  reopening one.
- **Escape does not close a sketch dialog, and it does not throw the sketch away.** A take that
  died between opening a sketch and drawing in it pressed Escape on its way out and left `Sketch 1`
  in the feature list. Clicking that row re-opens the same dialog instead of offering a context
  menu, so neither Rename nor Delete is reachable from it, and the toolbar Undo does not remove it.
  The dialog's red **×** is what discards it: on an empty sketch it takes the row with it. Any
  script that opens a sketch closes it with `gui.RED_X`, not with Escape.
- **`n` is not deterministic.** On the same Front plane in one session it gave a true Front view
  twice and the **Back** view once, with no rotation in between — and once it did not move the
  camera at all. **Check the view cube after every `n`.** A mirrored pass is harmless on symmetric
  geometry and silently wrong on anything else.
- **Pressing `n` again turns the view through the plane**, which is the way back from the mirrored
  side. The cheap test is arithmetic rather than the view cube: project the origin and a point ten
  millimeters along the model's own x, and read the sign. On the front of the Front plane the
  second point draws to the right of the first and level with it; from behind it draws to the
  left.
- **`n` moves the origin on screen.** Orienting normal to a plane re-frames the camera, so pixel
  coordinates worked out before the keystroke point at the wrong place after it. Run 6 drew a
  collar circle 85 px below the origin that way. Re-find the origin after every `n`.
- **`shift+s` means two different things depending on where you are.** Outside a sketch it opens
  one; inside a sketch it is the **Point** tool. Do not use it to open a sketch from within a
  sketch you have just closed by hand, because the mode may not have changed yet.
- **The sketch shortcuts worth knowing**: **g** corner rectangle, **r** center point rectangle,
  **shift+e** extrude, **n** view normal to, **shift+7** isometric, **f** zoom to fit.
- **A sketch pattern's instance count needs a double-click** to open its inline box; a single
  click only selects the manipulator. **Click somewhere empty in the graphics area to settle the
  pattern** — it has no green ✓ of its own. **Escape discards it**, and nothing says so: the sketch
  still closes clean and still reads fully defined. The tell is the next extrude previewing one
  instance where you asked for four.
- **Keyboard shortcuts go to whatever you last clicked.** After clicking a checkbox in the sketch
  dialog, pressing `g` did nothing at all — focus was still on the checkbox. When a dialog control
  was the last thing you touched, use the toolbar button, not the shortcut.
- Useful keys, all verified: `l` line, `g` corner rectangle, `r` center point rectangle,
  `c` circle, `d` dimension, `q` construction toggle, `i` coincident, `e` equal,
  `shift+q` symmetric, `shift+o` concentric, `shift+e` extrude, `shift+w` revolve.
- **`d` toggles the Dimension tool, and the tool survives between actions.** Pressing it when the
  tool is already lit puts it down, and the next pick then reports *"A dimension cannot be created
  between these items."* or opens no box at all. Ask before pressing: read the toolbar button's
  grandparent `div` and test its class for `is-active`.
- **The solver relocates an under-defined entity the moment you dimension it.** A circle drawn
  265 px above the origin jumped to 548 px when its diameter went in, and the follow-up click on
  its center hit empty canvas. Re-shoot and re-find the entity after every dimension.
- **Typing a value while drawing does nothing.** The live readout looks editable; it is not.
  Digits are discarded and Enter commits whatever the cursor was at. Double-clicking that
  readout makes it worse — one run got a `Ø0` label with no clean way back and restarted the
  sketch.
- **Dimension, then press Enter.** Pressing Escape to put the tool down *discards the number you
  just typed* and keeps the dragged size. The sketch still goes black. This produced a 34.8 mm
  torso where 48 was asked for.
- **Enter is not a guarantee either.** Run 2 saw a typed value silently discarded **twice in
  eleven** dimensions — edit box focused, value confirmed present by reading `input_value()` back,
  Enter pressed — and the dimension committed at the *dragged* size. **Read the label back off a
  screenshot after every dimension.** Double-click and retype fixes it every time.
- **A sketch has no axes to pick.** A symmetric relation wants a line and two things of the same
  type, and the sketch's vertical is not drawn anywhere, so there is nothing to take. A click
  where it would be lands on the solid behind the sketch and takes a point on one of its edges;
  Onshape then says *A symmetry constraint requires a line and two other geometries of the same
  type* and adds nothing. Hold a shape in the middle with a dimension from the origin, or draw a
  construction line and be symmetric about that.
- **A complaint about a relation arrives as a yellow bar, not as a feature error.**
  `gui_steps.errors` reads the feature list, finds nothing wrong and returns an empty set while
  the bar sits across the top of the window saying what was refused. The bar's words are plain
  text in the page, so read them back after asking for a relation.
- **A line drawn by clicking is vertical only if the pointer was inside the inference.** The
  head's profile came out with its left side leaning by a quarter of a millimeter, off a click a
  pixel wide of true, and nothing on screen said so. Ask for the relation rather than hoping for
  it, and read the closed sketch's geometry back before believing it.
- **Which dimension an ellipse gives you is decided by where the label is dropped.** Pick the
  ellipse and drop the label above it for the long way across; pick it again and drop the label
  out to the side for the short way up. Both are diameters, so a variable holding a radius is
  doubled in the box.
- **There is no readable `Under defined` anywhere in the page.** A scan of every childless `div`
  and `span` for the word came back empty while a sketch was plainly under-defined, so a script
  cannot ask the page whether a sketch is solved. Read the geometry back through
  `sketches?includeGeometry=true` once the sketch is closed. **A read taken while the sketch is
  still open answers with the last committed geometry**, so it cannot tell a constraint that took
  from one that did not, and it reads as failure either way. Four repairs to `ear wedge outline`
  were applied, checked against that read, and thrown away by the dialog's red **×** before the
  gate was moved to the screen.
- **A blue-pixel test for an under-defined entity starts right of the feature panel.** Onshape
  draws such an entity in a saturated blue, near RGB (65, 66, 254), and a scan for it is the only
  way to read a sketch's state while its editor is open. The sketch dialog's own checkboxes are
  that same blue, so a scan that begins at the window's left edge finds three of them in every
  frame and calls a solved sketch unsolved.
- **The label click has to clear the sketch axes, not only the model.** A width label placed
  straight above the rectangle landed on the vertical axis, which joined that line to the
  dimension: the readout became a 270° angle between the top edge and the axis, and no edit box
  opened. Nothing on screen says the pick went wrong except the angle itself. Offset the label
  sideways as well as away.
- **The label-placement click has a dead zone near the bottom of the canvas.** A label placed at
  y = 955 of a 1000 px window aborted the whole dimension — no box, no error, tool disarmed. The
  same dimension worked with the label at y = 790. If a dimension "does nothing", move the label
  click inward before suspecting the entity pick.
- **Draw arcs before the lines that meet them.** Dropping an arc onto a line's free endpoint
  constrains the arc to the *line*, not to the point, leaving the endpoint free to slide. The
  region still shades and every line goes black; a single blue dot is the only tell. Repairing
  it by adding Coincident over-constrains the sketch instead.
- **Black lines can still have blue endpoints.** Look at the dots, and drag anything blue.
- **A center point rectangle's corner click snaps to the sketch axis** if it lands within about
  10 px of one, and the rectangle comes out zero-width. Put the corner well clear and dimension it
  down afterwards.
- **Two parallel-line picks do not always give you the distance between them.** The Dimension tool
  sometimes reads the pair as one line and offers its *length*. It pre-filled 12 mm for a gap of
  4.4; typing 0.8 over that drove the wrong entity and the sketch went red. **Read the pre-filled
  value and check its magnitude before typing.** A single-edge length dimension is the
  unambiguous pick where the geometry allows it.
- **Escape clears a selection; clicking empty canvas does not.** A click meant for empty space
  lands on the part face behind it, and the status bar quietly starts reporting that face.

- **The Slot tool does not draw a slot.** Its tooltip reads *create a slot around continuous
  sketch entities*: it wraps something already drawn. Draw a **line**, arm Slot, click the line,
  move the mouse to set the width, and click. Clicking it on bare face does nothing at all, which
  reads exactly like a broken tool.
- **Arm the tool first, then pick the curve.** Arming Slot from the offset button's dropdown clears
  whatever was selected, so a line picked beforehand is not the line the tool gets, and the run ends
  with the line still there and no slot. Picking the line and then arming from the *tool search*
  does keep the selection, which is why the two orders read as one working and one broken.
- **The width click leaves a preview, and Enter is what keeps it.** Escape at that point takes the
  slot away and leaves the line and its dimensions, so the screen looks exactly as it did before the
  tool was armed. Committing with Enter came back Ø20 from a click 5 mm off the line, so the width
  the preview showed is not the width that lands: measure the slot, then edit its own diameter.
- **A tool in progress does not survive a script boundary.** Arm, pick, move and commit have to
  run inside one Playwright invocation; a second invocation that only sends the commit click does
  nothing. A *placed* dimension's edit box does survive, so reading and filling it in the next
  script is fine.
- **The Slot preview is far bigger than a tight crop.** A stadium spanning most of the model looks
  like nothing happened if the screenshot is clipped to where the slot was meant to be. Read the
  full frame before deciding an attempt failed.
- **Slot brings its own `DIAMETER` constraint** on `endCap`, with `labelRatio` 4 — the label sits
  four radii from the cap center, which is off-screen at any working zoom. Adding a second width
  or radius dimension over-constrains and gives *"Sketch could not be solved."* Zoom out, find the
  `Ø` label, and edit that one.
- **A failed dimension attempt leaves a driven `RADIUS` reference dimension behind.** Undo restores
  the previous *value* and leaves the dimension in place. Click the label once to select it and
  press Delete, then read the constraint list back over REST to prove it is gone.
- **Double-clicking a dimension label opens its edit box.** Verified on a `Ø20` label at
  (1020, 97). It does not work everywhere — one attempt at (1240, 616) highlighted the label tan
  and opened nothing — so read `document.activeElement.tagName` before typing.
- **The toolbar Undo button is at (57, 58) and works when `Ctrl+Z` does not.** `Ctrl+Z` sent to the
  graphics area did not undo a slot.
- **Constrain an ellipse Horizontal before dimensioning it.** It has a major axis, a minor axis and
  an angle; pinning the angle first makes the two diameter dimensions land where you expect.
- **A slot's center line does not split its region.** One Extrude click takes the whole stadium.
- **Sketch toolbar x-positions, y = 58**: line 193, rectangle 245, ellipse 297, arc 349,
  polygon 401, spline 453, point 511, text 538, use 574, construction 626, fillet 664, trim 717,
  slot 767 (its flyout caret 796, holding one item *Slot* at (761, 129)), mirror 819,
  linear pattern 854, dxf 906, dimension 962, constraint 1000 (caret 1028).
- **Constraint flyout geometry**: caret (1033, 58); items at x = 1009 — coincident 94,
  concentric 130, parallel 166, tangent 200, horizontal 236, vertical 272, perpendicular 307,
  equal 343, midpoint 379, normal 414, pierce 449, symmetric 485, fix 521, equal-curvature 556.

## 8. Measuring

The techniques below that work off a face dump are modules in `stickbot`, each taking
the JSON and printing its answer: `measure_walls.py` for concentric walls, `measure_planes.py` for
flat ones, `measure_gaps.py` for the closest approach between any two faces, `measure_solid.py` to
say which of those are plastic, `measure_line.py` to march a line through the part, and
`measure_tangency.py` for the crease angle at every edge. Read the docstring at the top of each for
what it can and cannot see.

- **There is no measure dialog.** Select one entity and read the **bottom-right of the graphics
  area**: an edge gives `Diameter`, a spherical face `Radius`, a planar face `Area`.
- **Verify what is in the selection list before trusting a number.** A "click empty space to
  clear" that lands on geometry leaves the panel summing two faces, and the result looks
  plausible. Run 1 lost ~15 minutes to a face area that was real arithmetic on the wrong set.
- Volume and mass properties: the **Display mass and section properties** icon, bottom right,
  then *Parts to measure*.
- **`POST .../featurescript` is the measuring tool this project kept missing.** `evDistance`
  between two bodies gives minimum clearance directly — that is how run 2 proved its two parts do
  not touch. A loop over `evPlane` for faces whose normal lies on an axis prints a whole stackup
  as a list of numbers. `evCurveDefinition` on every edge gives you every radius in the model in
  one call. Cookie auth plus the `X-XSRF-TOKEN` header is enough.
- **Measure the thinnest wall anywhere**, not the one you were thinking about. Run 2's hinge had a
  0.26 mm rim nobody had considered while everyone watched a 1.0 mm web that was fine.
- **Count the planes to tell an open pocket from a sealed void.** A blind cut that opens on a face
  contributes one plane, its floor; the same cut buried inside the solid contributes two, floor
  and roof, and removes exactly the same volume. Run 6's valley cut ran inward instead of outward
  and the 20-vs-19 plane count is what showed it, before any picture did.
- **When `featurescript` is 429, `bodydetails` still measures every shelled wall exactly.** Shell
  offsets each face inward, so a shelled surface and its offset **share an origin and an axis and
  differ only in radius** — and that radius gap *is* the wall. Group the dump's faces by
  `(origin, axis)`, take `abs(r1 - r2)` within each group, and you have every shell wall in the
  part with no estimation anywhere. It is exhaustive over concentric pairs and **blind to
  everything else** — a flat cut face approaching a curved one is exactly what it cannot see — so
  say which of the two you measured. `evDistance` is still the tool for the rest.
- **Flat walls need the material side, not just the spacing.** Two parallel planes 0.3 apart are a
  wall if plastic is between them and a gap if it is not, and the distance cannot tell you which.
  The dump can: each face carries `orientation` and its surface carries `isOrientedWithFace`, and
  the product of the two turned into the surface normal is the face's **outward** normal, which
  points away from material. So a pair is a wall only when the two outward normals oppose *and*
  point out of the space between them; every other close pair is a void. Skip this test and a
  shelled part reports thin walls it does not have — a boss standing 1.5 proud of a 1.2 shell
  leaves a 0.3 air gap at every one of them.
- **A throttled `featurescript` does not stop you measuring: `GET .../tessellatedfaces` answers
  200.** It returns triangles for **every** face, including the ones `bodydetails` gives up on and
  types `OTHER` with no geometry at all, so it reaches the cases the two searches above cannot —
  flat against curved, swept faces, fillets. Ask for a chord tolerance (`chordTolerance=0.0002`,
  `angleTolerance=0.02`) and expect a large answer: a 36 mm part came back as 185,582 facets and
  101 MB, so write it to a file rather than holding it, and do not commit it.
- **Do not pull a tessellation through `page.evaluate`.** It has to serialize the whole response
  across CDP, and past about 100 MB the tab dies — `TargetClosedError: Target page, context or
  browser has been closed`, with the browser itself still fine, so it reads like a dropped session
  when it is not. Use the browser context's own request object instead: `ctx.request.get(url,
  headers={'X-XSRF-TOKEN': …})` shares the signed-in cookie jar and streams straight to a file.
  `bodydetails` is small enough either way.
- **Size the tolerance to the part, or the request never finishes.** The same
  `chordTolerance=0.0002` that took 101 MB on the head did not return for the torso inside ten
  minutes; at `chordTolerance=0.001, angleTolerance=0.1` the torso came back in under four, at
  15.9 MB. Coarser costs accuracy — facet normals then lag the true surface by up to the angle
  tolerance, about 5.7° at 0.1 rad — so choose it against the smallest thing you mean to measure,
  not by what downloads fastest.
- **With the triangles you have the closed boundary, and that is enough for two things a kernel
  would normally do.** Closest approach between two faces: put every vertex in a spatial grid and
  compare only across cells, skipping pairs that share an `edgeId` because adjacent faces meet and
  the zero means nothing. Inside or outside: fire a ray and count crossings, odd is inside. Together
  they answer *thinnest wall anywhere* — the grid finds the close pairs, and the ray test says which
  are plastic and which are a slit.
- **Tangency is measurable, and looking at a render is not measuring it.** A render only shows that
  no crease is *visible*. Two faces meeting tangentially share a normal along their common edge, so
  take every pair that shares an `edgeId`, find the vertices they have in common in the
  tessellation, and compare the facet normals across them: zero degrees is tangent, anything else is
  a crease of that many degrees. Allow the angle tolerance you asked the tessellation for — at 0.02
  rad a true tangency reads as about half a degree, not zero. Then check the answer against
  `bodydetails`, where tangency is exact and always the same relation: the distance from an arc's
  axis to the line it meets equals the arc's radius.
- **Two faces can also come close by both running out at the same edge**, and then the midpoint sits
  exactly on the surface and the ray test is a coin toss. That number is the width of the land left
  between them, not a thickness. March a line inward instead and read the solid run: 1.2 of material
  behind a 0.4 gap means a narrow strip of face, not a thin wall.
- To measure into a cavity you must hide the part in front **and** right-click any plane →
  **Hide all planes**, or a plane sits between camera and target and swallows every click.
- **Hide applies to the whole current selection.** Hiding one part while another is still
  selected hides both, with no error and a blank screen.

## 9. Rendering the model, and looking at it

```
GET /api/partstudios/d/{d}/w/{w}/e/{e}/shadedviews?viewMatrix=isometric&outputHeight=900&outputWidth=900&pixelSize=0&edges=show&useAntiAliasing=true
```

returns `{images: [<base64 png>]}`, rendered server-side. Per part:
`/api/parts/d/{d}/w/{w}/e/{e}/partid/{pid}/shadedviews`, which frames that part alone.

`viewMatrix` takes `isometric`, `front`, `top`, `right`, `back`, `bottom`, `left`.

**Render every part on its own, from at least three angles, and look at the images.** A
whole-model isometric hides everything interesting: in run 1 a joint's entire fork was invisible
in all four standard views because the parts overlapped along the camera axis.

The view menu has *Isometric / Dimetric / Trimetric*, *Zoom to fit* and *Section view…* — but
**no Top/Bottom/Front entries**. Right-drag rotates, middle-drag pans, `n` is View normal to.

**Zoom to fit frames the default planes, not the part.** The planes are far larger than anything
this robot is made of, so `f` on a Ø9.4 collar leaves it a smudge in the middle of the window.
Hide Top, Front and Right first and `f` then frames the part.

**Sketches stay shown after you close them**, and `f` frames their union. A Ø20 circle came back
at 12.9 px per mm instead of 42.6 because a 100 mm rectangle two sketches earlier was still on
screen.

**Zoom to fit is exact arithmetic.** For a canvas W×H it sets
`scale = min(W / (1.05 * bbox_w), H / (1.05 * bbox_h))` and puts the bounding box's center on the
canvas center — a 5 % margin on whichever axis binds, not a fixed one in pixels. It is a home you
can return to: `f` gave 42.5714 px per mm at (923.0, 523.0) before and after an arbitrary scroll,
to the digit, and the same computed pixel selected the same circle both times.

**One wheel event multiplies the scale by 2^(1/12)**, 1.059463 — a semitone, twelve notches to a
doubling — whatever `deltaY` magnitude you send. So `round(12 * log2(target / current))` events
put you on a scale you choose. **Negative `deltaY` zooms in**, positive zooms out.

**`gui.zoom_to`'s target is pixels per millimeter, not millimeters across the canvas.** They run
opposite ways, so a number chosen as *how much of the model I want to see* zooms in when it should
zoom out. A 96 mm foot on a 1350 px canvas wants about 9; a 45 mm fork end wants about 13. Passing
140 puts you inside the part.

**Zooming keeps the point under the pointer still, which leaves it wherever it already was.** A
connector two thirds of the way down the canvas is still two thirds of the way down after the
zoom, and at a close scale that puts it off the edge. Pan it to the canvas center *first* — middle
drag from its projected pixel to `screen.CENTER` — then zoom about it, then pan again, because the
zoom moves it back. Re-project after every one of those, since each changes the camera.

**The view cube's arrow triangles turn 15° per click, not 90°.** Two clicks look like nothing
happened. Front to Left is six of them, and a seventh is what run 6 needed to see one ear's
domes past the other ear.

**To get a true orthographic view on screen, click a *face* of the view cube.** The cube's face
snaps the camera square and its label then names the view you are in, which is the confirmation
`n` never gives you. The cube's arrow triangles and its roll arcs produce partial rotations that
are hard to predict, and *View normal to* on the Front plane has come back 180° rolled. The view
menu's items are not `li` elements — scrape everything to the right of the canvas edge instead.

## 10. Read-only REST, for verification only

Same-origin `fetch` from inside the Onshape page. Cookie auth alone gives **401 on writes**; echo
the `XSRF-TOKEN` cookie back as an `X-XSRF-TOKEN` header. Full details and the encodings are in
[`onshape-api.md`](onshape-api.md).

Most useful for checking your own work:

- `GET .../features` — read `featureStates`; it is an **array of {key, value} pairs**, not a map.
- `GET .../parts/.../boundingboxes` — **the only thing that caught a rod extruded the wrong way**
  in run 1. Preview and isometric both looked fine. **Check a bounding box after any extrude that
  uses a starting offset.**
- `POST .../featurescript` — evaluate arbitrary FeatureScript against the model. Returns
  `{result, notices}`, and the notices carry real error text with line numbers.

**`massproperties` can hand back a center of mass of zero.** The head read
`centroid [0, 0, 0, -1e-06, -1e-06, -1e-06, 1e-06, 1e-06, 1e-06]` while sitting plainly off
center, so the middle of a part is not a number to test against. `bodydetails` gives each face's
`origin` in millimeters and answers the same questions properly: which way a cut ran, how deep it
went, and how many faces of each kind the part has.

**Read `expression`, not `value`.** `GET .../features` returns each quantity as
`expression: "1.35 mm"` with `value: 0` beside it. Reading `expression` is how run 2 pinned a
direction bug: the depths were right and `oppositeDirection: true` was the culprit.

**A Variable feature stores one expression per variable type, and only the typed one drives the
model.** `assignVariable` carries a `variableType` enum and the parameters `lengthValue`,
`angleValue`, `numberValue` and `anyValue`, with a generic `value` beside them that nothing
evaluates. Writing `value` alone is accepted, `GET .../features` reads the new expression back,
every feature status stays `OK`, and the geometry does not move. Write the parameter the type
names, and write `value` with it so the two cannot disagree.

**Read a change off the model, not off the feature you wrote it into.** `getVariable` in a
`POST .../featurescript` at the end of the tree, or a face census off `bodydetails`, tells a change
that reached the geometry from one that did not. In draft9p1p6 the feature said `#wedges = 24`, the
model said 12, and `#ring_out` answered `#flat - 0.4 mm` evaluated against the *new* `#flat`, so
even the stale value tracked its inputs and looked alive.

**Onshape's copy and version routes drop the `d/`.**
`POST /documents/{did}/workspaces/{wid}/copy` and `POST /documents/{did}/versions` answer;
`POST /documents/d/{did}/workspaces/{wid}/copy` and `POST /documents/d/{did}/w/{wid}/versions`
answer 404, which reads as a missing document rather than a missing prefix. A `GET` on the same
shape tells them apart before a write does.

**429 arrives late and is per-endpoint.** One run hit it on every call from the start and had to
take every number off the GUI readout. Another sailed through ~90 calls and then had `/features`
start returning `{"message":"Too many requests."}` while `/parts`, `/massproperties` and
`/featurescript` kept working. **`GET /features` returning `{"features":[]}` with status 200 is
not how it fails — check the status.** Do not build a verification plan that only works if REST
answers.

**429 clears in about a minute and a half of silence, and retrying resets the clock.** The one
place it was clocked end to end is
[`experiments/runs/2026-08-12-run3/torso/steps.log`](experiments/runs/2026-08-12-run3/torso/steps.log):
first 429 at 04:17:31, a 45 s backoff, one more failed attempt, then 200 at 04:18:54 — **83
seconds**. Against that, a retry loop of eight attempts at 20 s apart never recovered at all, and
run 5 recorded `featurescript` as 429 "for the whole second half of the run" while still calling.
Treat it as a bucket that only refills while you are not drawing on it: stop calling entirely,
wait longer than you think, then make **one** request. Polling is what turns a 90-second pause
into an outage that lasts as long as you keep polling.

**But 83 seconds is not the only kind of 429.** On 2026-08-14 `/features` on the torso stayed 429
through more than fifteen minutes of silence, with `/companies` answering 200 the whole time, so
the session was fine and one endpoint was not. Run 5 saw the same endpoint stay 429 for half a
run. **Plan for a route that does not need `/features` at all** — the GUI, or `bodydetails` and
`tessellatedfaces`, which both kept answering here.

**The longer one is a spent quota, and it says so in the headers.** Read on 2026-08-27: `/features`
answered `retry-after: 67201` — 18 hours 40 minutes — beside `x-rate-limit-remaining: 0`, and the
number counted down with the clock rather than resetting when the calls stopped. So the two kinds
are told apart by asking, not by waiting and seeing: a burst block either names a short wait or
names none, and a quota names hours. [`onshape-api.md`](onshape-api.md) § *Rate limits* carries the
endpoints that stayed open, and `api()` in
[`../src/stickbot/onshape_session.py`](../src/stickbot/onshape_session.py) now reads the header and
stops instead of laddering.

## 11. Housekeeping the report depends on

- **Rename features and parts as you go.** `Extrude 4` tells the next reader nothing, and run 1's
  hinge shipped with every feature unnamed.
- **Publish a named version before writing the report** — left rail → **Create version…**, the
  top icon, above Comments. A report citing only a workspace has recorded a moving target. The
  GUI route always works; if `POST .../versions` comes back 401 while `GET` on the same path
  answers 200, suspect a truncated XSRF token before concluding the endpoint is closed — see
  [`onshape-api.md`](onshape-api.md).
- **The left rail's buttons carry no label of any kind.** No `aria-label`, no `title`, no
  `data-automation`; a search for a button whose label says *version* finds nothing. Each one's
  `svg` `<use>` names its sprite instead, and the one to click is
  `#svg-icon-create-version-button`. The rail reads, top to bottom,
  `versions-history-panel`, `create-version-button`, `comments-panel`, `notes-panel`,
  `performance-panel`, `onshape-ai-advisor-button`, `action-items`.
- **The Create-version dialog's confirm button carries no `data-automation`.** It is a plain
  `<button>` whose text is `Create`; `[data-automation=ok-button]` times out. And the dialog is
  the reason to publish through the GUI at all when a page needs a frame of it — REST never shows
  it.
- **A version cannot be renamed from its context menu.** There is no *Rename*; use
  **Properties…** → edit the name → **Save**. Two versions are allowed to hold the same name, and
  nothing warns you, so a second publish under a name already used leaves the citation ambiguous.
- **Clicking a version parks the browser inside it, view-only**, and every frame taken afterwards
  carries a *Versions are view only* banner. **Return to Main** before shooting anything.
- **Deleting the tab you are looking at leaves an undismissable banner** — *Can't open tab. The
  tab does not exist in this document work* — with no ×, so `no_banner` retries and raises.
  `page.goto` the URL of a tab that still exists; the reload clears it.
- **`page.mouse.click` has no `modifiers` keyword.** For a shift-click, bracket the click with
  `page.keyboard.down("Shift")` and `.up("Shift")`.
- **There is no *hide planes* in the view menu.** Select Top, Front and Right in the feature tree
  (shift-click, per the line above), then right-click → **Hide**. A tree row's context menu
  sometimes needs a plain left-click first, and the very first right-click after a fresh CDP
  connect can be swallowed entirely — click again rather than concluding the row is wrong.
- **`featureStates` in the features response is a list of `{key, value}` wrappers**, not a dict.
  `.items()` raises and `s["message"]` raises; read `s["value"]["message"]["featureStatus"]`.
- **A `TargetClosedError` after `gui.tick()` does not mean the action failed.** It has fired with
  the browser alive and the feature committed; check the model before re-running anything.
- **The left-rail icons carry no `title` or `aria-label`.** Hover each and read the tooltip out of
  the DOM; do not count rows to guess which is which, because the rail's contents change with the
  tab you are on.
- **Take every click through [`../src/stickbot/onshape_gui.py`](../src/stickbot/onshape_gui.py).**
  Its guards are what stop a bad frame shipping: it refuses to shoot through a notification banner
  or a moving screen, checks that a canvas pick selected something, and reads every typed number
  back out of its field. [`onshape_screen.py`](../src/stickbot/onshape_screen.py) answers where
  things are — by reading the pixels, and by projecting a model point through the camera it reads
  off the GPU. [`onshape_record.py`](../src/stickbot/onshape_record.py) records a stage as video.
  How a capture is conducted is [`build/takes.md`](build/takes.md).
- **[`../src/stickbot/gui_steps.py`](../src/stickbot/gui_steps.py) is superseded** by those. It was
  the earlier choke point, and its numbered frames and `steps.log` belong to the wave-of-agents
  cycle that `build/takes.md` replaces.

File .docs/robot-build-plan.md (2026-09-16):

# The robot — build plan and course coverage

An articulated figure, about 300 mm tall, modeled the way the Onshape courses teach it. 

The "about 300 mm" above is a target the stations were fitted to in an early version of the figure.
There is no requirement for the exact height of the figure because driving the design to a specific
height forces unneeded work. The program `make_plans.py` determines the sizes.

This plan exists
to answer one question: **how much of the official curriculum can one model actually carry,
and what does it leave out?**

Coverage is measured against the three courses as crawled from the Learning Center — every
lesson name, every Key Takeaway, and all fourteen slides of *Available Constraints*. The
checklists below are their lesson lists, not a paraphrase.

## Nothing here is settled until the whole robot is printed

**TODO — print the entire robot, assemble it, and operate it.** Every number in this plan and in
the briefs it points at has been decided in CAD, checked against arithmetic, and in a few places
measured on a printed part. None of that is the same as a robot that prints, snaps together and
still holds its pose after a class has played with it.

**Where a calculation and a print disagree, the print wins.** The hinge's fingers are the worked
example. Run 5 built the ear at **1.2**, and the arithmetic said that was safe — an 8 % margin on
stress. Printed, those fingers splayed over the axle stubs and stayed splayed. The calculation was
not wrong; it asked whether the finger would break, and the finger did not break, it stopped
coming back. The ear is 3.0 because of that print. See
[`experiments/build-briefs/hinge.md`](experiments/build-briefs/hinge.md).

**What the calculations here leave out**, and what a print would put back: whether a finger bends
along its length or at a root, permanent set after the first assembly, infill ratio, infill
pattern, and which axis each part is printed on. A number for one aspect of a printed assembly is
one aspect, and this robot has many that nothing here is paying attention to.

## The figure

Thirteen joints, of two kinds.

| Joint | Count | Type | Freedom |
| ----- | ----- | ---- | --- |
| Neck | 1 | ball and socket | 3 rotations |
| Shoulder | 2 | ball and socket | 3 rotations |
| Elbow | 2 | **hinge, detented** | 1 rotation |
| Wrist | 2 | ball and socket | 3 rotations |
| Hip | 2 | ball and socket | 3 rotations |
| Knee | 2 | **hinge, detented** | 1 rotation |
| Ankle | 2 | ball and socket | 3 rotations |

Elbows and knees are fork-and-blade hinges: a forked end on one limb, a flat tongue on the
other. **There is no pin.**

**The hinge started as LEGO's click joint and stopped being one.** The blade carries a Ø4 axle
standing 3.00 off each face of its tongue; each fork ear is bored Ø4.1 straight through on the same
line. Pinch the two leaves together, slide the tongue in, let go — the axle springs into the bores.
The mating faces carry **24 wedges, 15° apart**, on the tongue and on the ear alike: pie slices with
45° sides standing 0.75 proud, so a detent is one member's wedge sitting between two of the other's.
The joint clicks between positions and *holds a pose*. A friction hinge goes slack; a detented one
does not, and being poseable is the whole point of the figure.

**There are no holes in the joint, and that is the reason for the change.** The detent used to be a
cone dropping into a hole bored through the ear. The printer put supports in those holes, they could
not be cleaned out, and the printed joint held 210 N·mm where it was drawn for 454 — one extrusion
width of residue in a valley accounts for the whole loss. A protrusion has nothing to clean out.

Both halves are springs, and that is what lets a hand assemble it: a slit up the middle of the
tongue splits it into two leaves, tapered 4.20 at the root to 1.50 at the tip, and the leaf and the
ear share the movement in series. It takes **75.2 N** to pinch together and holds **641 N·mm**, or
1332 N·mm once friction on the 45° flanks is counted. The specification is
[`experiments/build-briefs/hinge.md`](experiments/build-briefs/hinge.md), the sweep that settled
every number is [`reviews/hinge/`](reviews/hinge/), and this section is the reasoning behind it.

What that trades away, stated plainly: a snapped pin used to come from the LEGO bin, and a
snapped stub means reprinting a limb. The 3.2 mm bar now has exactly one consumer — the gripper —
which is a cleaner story than the same number turning up in two unrelated places.

### One part per unique object

**The Part Studio holds one of each unique part. The assembly makes the copies.** A left arm
and a right arm are the same part inserted twice, not two parts modeled twice.

Drawn on two sheets, generated by
[`make_plans.py`](../src/stickbot/make_plans.py):
[sheet 1, assembled](../instructions/robot-guide/source/images/plan-assembly.png) and
[sheet 2, the eight parts](../instructions/robot-guide/source/images/plan-parts.png).
Sheet 2 names every
joint portion and carries a section through each of the two joint kinds.

| Part | Instances | Carries |
| ---- | --- | --- |
| Torso | 1 | five ball studs — neck, two shoulders, two hips |
| Head | 1 | neck socket |
| Upper arm | 2 | shoulder socket, elbow fork |
| Forearm | 2 | elbow blade, wrist ball |
| Gripper | 2 | wrist socket, LEGO C-clip |
| Thigh | 2 | hip socket, knee fork |
| Shin | 2 | knee blade, ankle ball |
| Foot | 2 | ankle socket |
| LEGO bar | — | what the grippers hold; not part of the robot |

**Eight modeled parts, fourteen printed instances.**

### Joint parts are added to main parts

A joint portion is not a detail of a part — it is **a part in its own right, added to a main
part.** A ball stud is modeled on its own and added to the torso. A socket is modeled on its
own and added to the head.

**Say "added" even when the Boolean is a subtract.** The socket is a part you add to the head;
that it arrives as a cavity is how it is built, not what it is. Keeping the word steady means
one sentence covers all fourteen, and it matches how the feature tree reads.

| Joint part | Added to | Arrives as |
| --- | --- | --- |
| neck ball stud | torso | material |
| shoulder ball stud | torso | material |
| hip ball stud | torso | material |
| wrist ball stud | forearm | material |
| ankle ball stud | shin | material |
| neck socket | head | a cavity |
| shoulder socket | upper arm | a cavity |
| hip socket | thigh | a cavity |
| wrist socket | gripper | a cavity |
| ankle socket | foot | a cavity |
| elbow fork | upper arm | material |
| knee fork | thigh | material |
| elbow blade | forearm | material |
| knee blade | shin | material |

On [sheet 2](../instructions/robot-guide/source/images/plan-parts.png) each of these is marked
with a **+**, so the drawing reads as *main part, plus the joint parts added to it.*

**Handedness is a design decision, and the answer is no.** A part that is its own mirror image
serves both sides; one that is not doubles the part count for nothing. So the foot is symmetric
about its own fore-and-aft centerline, and the gripper's C-clip opens forward rather than
outward.
Neither choice costs the design anything, and each one halves a part. Getting the part count
down by shaping the part is what a designer actually does, and it is invisible unless somebody
says it out loud.

**The feet are not handed, and they are allowed to touch.** The ankle socket sits on the foot's own
left-right centerline as well as its fore-and-aft one, so nothing in the part says which leg it
belongs to. Each foot then sits where its own leg does, at x ±24, and a 48 mm foot brings the two
inner edges together at x 0. **Feet touching when the legs and ankles hang straight down from the
hips is a stance the design accepts.** Every joint below the hip turns, so some pose always brings
the feet together; buying one pose back costs a left foot and a right foot, which is the thing this
design does not do.

**Everything is modeled in place, on the right-hand side.** Each limb sits at its own station
on the layout sketch, so a ball stud on the torso is already in position to be subtracted from
the socket that receives it. The left-hand stations stay empty in the Part Studio; the assembly
fills them.

## Variables

Every number the model dimensions with is declared in one of two places, and which of the two is a
rule rather than a preference: **a dimension read by two Part Studios is declared in the Variable
Studio.** Onshape scopes a variable to the Part Studio that declares it, so a second tab that needs
the same number has to re-declare it, and re-declaring is what lets two copies of one number drift
apart. Everything read by one tab stays in that tab, and the **Proportions** table below records
what each of those came from, so a later run can promote one without re-deriving it.

**The numbers here are the robot as it is built, at `#torsoH` 96.** This section carried the 48 mm
robot until draft9p1: the doubling reached `make_plans.py` and the build briefs and never reached
the document the Constitution calls the design source.

### The four that drive the robot's size

| Variable | mm | Meaning |
| --- | -- | --- |
| `#torsoH` | 96 | torso height |
| `#torsoW` | 72 | torso width — three quarters of the height, at the default proportions |
| `#torsoD` | 48 | torso depth — half the height, at the default proportions |
| `#limbCenter` | 48 | one limb segment, joint center to joint center |

`#limbCenter` spaces the joints, not the stock: hip to knee, knee to ankle, shoulder to elbow
and elbow to wrist are all this far apart, and each rod is then cut to whatever length puts
its two joint centers there. No two of the four rods come out the same length, because a
socket sinks its center inside the face and a ball stud stands its center clear of one.

The three torso numbers are independent, not expressions on each other. A student who wants a
stocky robot edits the width; one who wants a lanky one edits the height and `#limbCenter`.
That is the whole variable lesson the class spends time on.

### The ones the rule brings up with them

Two or more Part Studios read each of these, so each has one row in the Variable Studio and none in
the tabs that use it. The **read by** column is the reason the row is here.

| Variable | mm | From | Read by |
| --- | -- | ---- | --- |
| `#ball` | 12 | `#torsoH / 8` | `body`, `ball and socket`, `foot`, `gripper` |
| `#limbD` | 24 | `#torsoH / 4` | `body`, `hinge`, `u limb`, `l limb` |
| `#wall` | 1.8 | `#torsoH * 3 / 160` | `ball and socket`, `foot`, `gripper` |
| `#stand` | 10 | `#ball * 5 / 6` | `body`, `l limb` |
| `#collar` | 10 | `#stand`, so both halves of a joint reach the same distance | `ball and socket`, `foot` |
| `#fit` | 0.08 | **not scaled**; the printer decides it | `ball and socket`, and `#grip` in the row below |
| `#ballLoss` | 0.10 | **not scaled**; what a printed ball loses on its radius | `#grip` and `#mouth` |
| `#t_print` | 0.10 | **not scaled**; how far one printed surface lands off where it was drawn | `hinge` |
| `#grip` | 2.2205 | `sqrt((#ball / 2 + #fit) ^ 2 - (0.48 * #ball - #ballLoss) ^ 2)` | `ball and socket`, `foot` |
| `#blade` | 10 | typed; the hinge's tongue, and the width every other hinge number is set from | `hinge`, `l limb` |
| `#wedge_h` | 0.75 | typed; how far a wedge stands proud of its face | `hinge`, and `#gap` two rows below |
| `#wedge_c` | 0.15 | **not scaled**; the air over a wedge tip, which the printer decides | `hinge`, and `#gap` in the row below |
| `#gap` | 0.90 | `#wedge_h + #wedge_c` | `hinge`, and `#seat` in the row below |
| `#seat` | 11.80 | `#blade + 2 * #gap` | `hinge`, `u limb` |
| `#blade_out` | 32 | typed; how far the blade stands out of its own limb | `hinge`, `l limb` |
| `#slot_deep` | 33 | `#blade_out + 1` | `hinge`, `u limb` |
| `#tab_free` | 20 | `#blade_out - #limbD / 2` | `hinge`, `l limb` |
| `#ear_free` | 21 | `#slot_deep - #limbD / 2` | `hinge`, `u limb` |
| `#flat` | 10.4494 | `sqrt((#limbD / 2) ^ 2 - (#seat / 2) ^ 2)` | `hinge`, `u limb`, `l limb` |

**The hinge's rows are here because the hinge stopped being one Part Studio's business.** A limb
reads `#ear_free` or `#tab_free` to know where its rod stops, and both limbs read `#flat` to cut the
same two faces the fork is cut on, so a limb that types those numbers drifts from the joint it
carries the moment either moves. `#blade`, `#wedge_h` and `#wedge_c` come with them because the
rows above are computed from them and a Variable Studio row cannot read a Part Studio's.

**`#gap` stopped being a fit and became a space.** It used to be 0.15, the clearance the printer had
to hold between two faces resting on each other. The two faces no longer touch: each carries a ring
of wedges standing `#wedge_h` proud, and `#gap` is what that ring needs to stand in plus the
`#wedge_c` of air left over a tip at a detent. `#wedge_c` is the row the printer decides now, and it
has to clear twice the printer's error, because two surfaces face each other.

**Which tutorial types a row into the studio is not settled here.** The studio is one element and
rows go into it at any point in the build.
[`build/plan/01-torso.md`](build/plan/01-torso.md) puts the four drivers and `#wall` in the first
tutorial; the other six arrive with the parts that read them.

**Two rows carried a *not scaled* mark that did not hold.** `#wall` did scale, and the rule it
scales by has since changed twice: `#torsoH / 32` gave 3.0, and `#torsoH * 3 / 160` gives 1.8, which
is the wall `src/stickbot/socket_spring.py` says the socket needs. `#fit` does not scale and it
moved anyway: 0.2 here, 0.8 as draft9p0 built it, 0.08 now. Marking a number *not scaled* records
where it came from; it does not stop anyone changing it.

**`#collar` was typed with no reason to be, and is not any more.** It was 5.5 at the 48 mm robot
and 11 at this one, with nothing written down that produced both, so driving `#torsoH` past 96 grew
the ball it wraps and left the collar where it was. It is now `#stand`: a socket reaches back from
the ball's center exactly as far as a stud stands its ball clear of its own face, so both halves of
a joint give up the same length of limb and the joint is symmetric about the center it turns on.

### The ones the ball and socket keeps

Nothing outside the joint builds geometry from these, so they stay in the Part Studio that does.

| Variable | mm | From | Meaning |
| --- | -- | ---- | --- |
| `#stalk` | 6 | `#ball / 2` | the neck the ball stands on |
| `#slit` | 1.6 | typed | how wide each relief slit is |
| `#stud_len` | 10 | scaffolding | the stud's top face above the ball's center; on the robot the stalk grows out of a torso face instead |
| `#slit_in` | 3.679 | `sqrt((#ball / 2 + #fit) ^ 2 - (#ball / 3) ^ 2) - #wall / 2` | where a slit's inner end stops. Inside the mouth's 5.66, or the mouth cannot open, and inside the cavity where the slit bottoms out, or the cut ends blind |
| `#slit_d` | 6.2205 | `#grip + #ball / 3` | how deep a relief slit is cut, which is the fingers' free length |
| `#mouth` | 11.32 | `0.96 * #ball - 2 * #ballLoss` | the opening the ball snaps through |
| `#slit_out` | 12 | clear of the rim | where the slit ends — the collar's radius is 7.8, so it overshoots by 4.2 |

`#slit_out` and `#slit_d` were plain numbers through run 6 and got rows in run 8p1, so that the
slit sketch has no bare numbers left in it at all.

**`#stud_len` and `#mouth` are recorded here and are not variables in the tab.** The stud's top
face is `#stand` above the ball's center, which is what `#stand` means, so a second row for the same
height would be a number with two homes. The mouth is where the cavity sphere crosses the socket's
top face, so it follows from `#grip` and cannot be set independently of it.

### Proportions — recorded, not driven

These are variables too, each in the one Part Studio that reads it. The **From** column says where
the number came from, which is what makes promoting one to the Variable Studio a decision rather
than a re-derivation.

| Measurement | mm | From | Meaning |
| --- | -- | ---- | --- |
| head across | 72 | `#headW` = `#torsoW` | the head is as wide as the body |
| gripper length | 24 | `#gripperL` = `#torsoH / 4` | wrist center to the bottom of the gripper |
| clip radius | 5 | `#clipR`, typed | the C-clip that holds the bar |
| bar diameter | 3.2 | `#barD`, **not scaled** | LEGO decides this one |
| blade thickness | 10 | `#blade`, typed | the hinge's tongue |
| leaf at the root | 4.20 | `#leaf_root`, typed | one leaf, across, where it leaves the limb |
| leaf at the tip | 1.50 | `#leaf_tip`, typed | and at the tongue's tip; the leaf tapers |
| tongue slit | 1.60 | `#slit_h` = `#blade - 2 * #leaf_root` | the relief slit at its root, opening to 7.00 at the tip, so the tongue springs too |
| fork ear | 6.10 | `#ear` = `(#limbD - #seat) / 2` | whatever the seat leaves of the limb |
| hinge stub | 4 | `#stub`, typed | the axle across the blade, into a bore through each ear |
| axle proud | 3.00 | `#stub_proud` = `2 * #wedge_h + 1.50` | how far the axle stands off each face of the blade. It has to beat `2 * #wedge_h`, or the joint lets go of the pin every time it crosses a detent; the 1.50 is what is still in the bore while riding over a crest |
| bore | 4.1 | `#bore_d` = `#stub + 0.1` | the hole the axle turns in, 0.05 of clearance a side. That is inside one `#t_print`, so whether it is a clearance or an interference is a question about the printer |
| limb across the chord | 20.8988 | `#limb_flat` = `2 * #flat` | the limb, top to bottom, once both cuts are made |
| wedges | 24 | `#wedges`, typed | in a ring on each face of the tongue and on each ear, 15° apart, which divides 90 exactly |
| ring, outer | 10.4494 | `#ring_out` = `#flat` | how far a wedge runs out, which is right to the edge of the face: the ring touches the limb's top and bottom cut, and that is the longest lever the detent can act on |
| ring, inner | 6.00 | `#ring_in`, typed | and where it starts. It clears the Ø4.1 bore with 3.95 of boss left |
| where the fit is set | 9.9994 | `#wedge_bind` = `#ring_out - #gap / 2` | half way up the gap, which is also where the two radial draft ends have taken the least off the radius. One height and one radius settle the whole fit |
| what the draft leans | 5.1587° | `#wedge_inset` = `2 * asin(#gap / 2 / #wedge_bind)` | both flanks are drafted 45°, so each leans inward by its own height above its own face, and by mid-gap the two have leaned away from each other by the whole gap |
| room for a flank | 1.1460° | `#wedge_eps` = `2 * #t_print / #wedge_bind` | what a flank needs to clear at that radius. The clearance is a length; a pie slice's clearance is an angle |
| wedge, across | 11.5127° | `#wedge_w` = `180° / #wedges + #wedge_inset - #wedge_eps` | one wedge at its base, which is wider than a half step and has to be. Fit the two base sectors as if they shared a plane and the wedge comes out too narrow, and the joint turns most of a half step before it touches anything |
| backlash | 2.2920° | `#backlash` = `2 * #wedge_eps` | how far the joint turns at a detent before a flank touches, which is 15% of a step. It is the price of a joint that goes together at all |
| fork member rod | 17 | `#rod_fork` = `#limbCenter - #collar - #ear_free` | the upper limb's rod, socket to slot root |
| blade member rod | 18 | `#rod_blade` = `#limbCenter - #stand - #tab_free` | the lower limb's rod, tongue root to ball center |
| ankle height | 24 | `#ankle_h` = `#torsoH / 4` | ground to ankle center |
| foot length | 96 | `#foot_l` = `#torsoH` | foot length |
| foot width | 48 | `#foot_w` = `#torsoH / 2` | foot width |
| hip half-spacing | 24 | `#hip_half` = `#torsoW / 2 - #limbD / 2` | and it is the leg centerline: a leg's outer surface lands on the torso's side |
| shoulder half-spacing | 36 | `#shoulder_half` = `#torsoW / 2` | the torso's side face, where the shoulder stud roots |
| shoulder stud | 26 | `#shoulder_len` = `#torsoH * 13 / 48` | side face to shoulder ball center, along the stud |
| foot half-spacing | 24 | `#hip_half` | a foot sits where its leg does, because its ankle is on its own centerline. The assembly places the feet, so no tab declares this one |

**The clip radius has a row for the first time.** It is the one number in the robot set by something
outside it — a Ø3.2 LEGO bar — and it sat in neither table while both tables described numbers that
scale.

**The ear row used to read 1.2, and 1.2 was the ear that failed.** Run 5 printed a fork with an
ear that thick and the fingers splayed over the axle stubs and stayed splayed. The ear is
`(#limbD - #seat) / 2` and comes out 6.10, where `#seat` is the slot: 11.80, one width from the
fork's tip to its root. It fell from 6.85 when `#gap` grew and took 0.10 back when `#gap`
shrank, and the ear can afford either: the ear was never the soft member. The slot used to be
cut 11.2 with a raised land around the pin giving the fit back over the 20.8 the teeth needed;
the land came out on 2026-09-02, and the face it stood on came forward to where it was. Nothing
seats on that face now — it stands `#gap` off the tongue's and the two rings of wedges reach
across.

**The blade row recorded the other hinge.** `#torsoH / 16` gives 6.0 at this size, which is the
blade in `stickbot-for-bot-review`; `make_plans.py` draws 10.0 and draft9p0 built 10.0.
[`experiments/build-briefs/hinge.md`](experiments/build-briefs/hinge.md) carries both in one table
and says the row is not settled. The number above is 10.0, because that is what the sheets draw and
what the model is being edited to.

**Two rows became one.** Hip half-spacing and leg centerline were separate rows carrying the same
12, derived two different ways. They are one expression, `#torsoW / 2 - #limbD / 2`, and it is the
one that puts a leg's outer surface on the torso's side at any width —
[`experiments/runs/2026-08-25-draft9p1/a7-hip-shoulder.md`](experiments/runs/2026-08-25-draft9p1/a7-hip-shoulder.md)
has what the 1× robot got by coincidence instead.

**The arm centerline row is gone, because the arm has no centerline.** It read 27 — a shoulder
half-spacing plus a limb radius plus 3 mm of air — and it described an arm hanging square to a
torso. The shoulder is a stud leaving the side face 53° below horizontal and 30° toward the front,
so the arm hangs 33.13° off vertical in a plane 7.82 forward of the torso's center. What that row
was protecting is now the shoulder stud's own length: at 26 along the stud the ball stands 13.55
clear of the side face, the arm's whole arc is free of the torso, and the closest it comes anywhere
in that arc is 1.46.

**What *not scaled* means, now that `#wall` has lost the mark.** A number set by the printer, the
plastic or LEGO does not belong with the four that drive the robot's size, and `#barD` and `#fit`
are the two that qualify. That is a reason not to make one a driving variable; it is not a reason
not to make one a variable at all. Both have rows, because the model that uses them has to record
why they are what they are — a different job from making the robot bigger.

### Why the limbs are Ø12

Decided 2026-08-11. **This reverses a change made earlier the same day** — the limbs went to
Ø16 and came back — and the reversal is the instructive part.

**The robot has since doubled and the limbs are Ø24.** Everything below is the argument as it was
made, at the 48 mm robot. It is an argument about proportion rather than about 12: `#limbD` is
`#torsoH / 4`, and every fraction in it holds at either size.

The hinge build measured **0.200 mm of clevis wall per side** inside a Ø12 limb, and observed
that the clevis is a **12 × 11.6 paddle whose corners stood up to 2.5 mm proud** of the rod.
Both facts were real. The mistake was the response: we grew the limb to fit the joint, rather
than asking why the joint was that size.

The joint was that size because it had been **scaled off the torso instead of off the nozzle**.
A 6 mm blade is fifteen extrusion widths — far more material than a hinge this small needs.
Redesigning from the printer upward gives a **7.0 mm fork inside Ø12** with 2.2 mm of wall, and
then a second change removes the constraint altogether:

**The fork is drawn as slices of the limb, not as a rectangle inside it.** Each layer runs out
to the Ø12 arc instead of being cut off at a common width, so there is no rectangle, no corner,
and nothing to check. The ear gains 13 % of cross-section for free, and the blade's own corners
land exactly on the rod's surface.

| | Ø12, joint redesigned | Ø16, joint unchanged |
| --- | --- | --- |
| Clevis wall per side | 2.2 mm | 2.2 mm |
| Fraction of 48 | 48/4 | 48/3 |
| Legs against the torso sides | flush | 2 mm proud |
| Ball joint sweep | **78°** | 61° |
| Limb aspect over a 24 segment | 2 : 1 | 1.5 : 1 |

**The ball joint prefers Ø12 too, and that overturns the argument used to justify Ø16.** The
claim was that Ø16 gave the socket collar a bigger step-back — 3.3 mm a side against 1.3. True,
but backwards: the joint stops when the limb's own rim swings up to meet the mating part, and a
wider limb puts that rim further out. **What buys the swing is the collar's height, not the gap
around it.** Boring the socket straight into the limb face gives 56°; standing the collar
5.5 mm proud gives 78°.

**Two stations are relations rather than coordinates, and one of the two survived:**

- Leg centerline = shoulder half-spacing − limb dia/2 = 12. A leg's outer surface lands on the
  torso's side — true at Ø12 by coincidence before, stated now. It is `#hip_half` today, and 24.
- Arm centerline = shoulder half-spacing + limb dia/2 + 3 = 27, keeping 3 mm of air. This one went
  when the shoulder moved onto an angled stud: the arm hangs 33.13° off vertical, so it has no
  centerline, and the clearance is bought by the stud's length instead.

Both were hard-coded when the diameter changed, and had to be recomputed by hand because nothing
recorded what they were derived from. Written down as relations, the next change to the diameter is
arithmetic somebody redoes rather than a discrepancy somebody has to find.

**Settled by run 3, and it is why the part is called a gripper.** The C-clip is Ø10 against a
Ø12 wrist, so the widest thing on the arm is the limb and everything below it tapers. That is
why it does not read as a hand, and no diameter fixes it that the socket survives — Ø14 wants
the gripper length at 17.2. The clip radius has a row of its own now, at 5.

**96 is chosen, not rounded.** 2⁵ × 3 divides evenly by 2, 3, 4, 6, 8, 12, 16, 24 and 32, so every
fraction of the torso lands on a whole millimeter — no `33.75` anywhere in the model, and no
dimension that reads like a rounding error. The robot stands **318**, and the stations are what
`make_plans.py` draws:

| Station | mm from ground |
| --- | --- |
| ankle | 24 |
| knee | 72 |
| gripper, bottom, elbow bent 45° | 86.58 |
| mid thigh | 96 |
| wrist | 110.06 |
| hip | 120 |
| elbow | 157.04 |
| shoulder | 197.24 |
| neck | 236 |
| top of head | **318** |

**Every station up the spine is whole, and none of the arm's is.** The legs are two `#limbCenter`
segments and an ankle, all fractions of `#torsoH`, and the head sits a `#collar` and a `#torsoW`
above the neck. The arm hangs off a stud at 53° and 30°, so its stations are that stud resolved into
two directions, and no angle that is not 0, 30, 45, 60 or 90 gives a whole number of millimeters.

**The arms reach mid-thigh, and that is still a relation rather than a number.** Shoulder to the
bottom of the gripper is `2 × #limbCenter` + `#gripperL`, 120 along a straight arm; the arm hangs
33.13° off vertical, so it drops 100.49 and the gripper's bottom lands at **96.74** against a
mid-thigh of 96. The relation was set on an arm hanging square to the torso and the angled stud
cost it 0.74 mm.

The torso comes out **48 × 72 × 96** — a 2 : 3 : 4 box — and the foot is 96 long, the same as
the torso is tall. Proportions worth being able to say out loud are proportions students
remember.

The bar diameter is marked **not scaled** for a reason. Scale the robot to twice the size and
the gripper still has to grip a 3.2 mm bar, because the bar does not scale. A model that teaches
nothing else about interfaces teaches that.

### Why any, when the courses teach none

None of the three courses mentions variables — the word does not appear once across 72
lessons. Four drive the robot anyway, because the torso box and the limb length are the numbers a
student changes to make the robot their own, and typing each of them in six places is how a robot
ends up with a 36 mm torso and a 33.75 mm hole in it.

The joint's own five, and the six that come up into the studio with the drivers, are there for
the other half of what a variable is for. A student who reads
`#collar - #wall` in a dimension box learns the depth of the cut from the box, which is a lesson
one Part Studio can teach in the time it takes to type it.

Everything in the **Proportions** table is declared in the one Part Studio that reads it, and its
proportion is recorded there rather than carried by the Variable Studio: the class gets the lesson
that one number can drive a shape without spending the first tutorial typing twenty rows. The rule
that keeps it honest is unchanged — **variables carry proportion, the layout sketch carries
position.** Anything that says *where* lives in the sketch as a constraint.

## The layout sketch

Everything hangs off a single fully-constrained sketch on the Front plane, made of
construction geometry: a vertical centerline, a horizontal station line at every joint
height, and a point at every joint center. It carries no shape at all.

**The origin sits at the center of the torso**, placed by a center point rectangle. That makes
the torso symmetric about the origin in both directions with no dimension at all, and it is
the part that gets fixed to the assembly origin later — which is exactly what the Assemblies
course means by "always fix a single part to the assembly origin". The ground line therefore
sits at a negative station, −84 mm, and that is fine.

Every later sketch reaches back with **Use (Project/Convert)** and constrains its geometry to
the projection. Three rules make it hold:

1. **Nothing downstream carries its own position dimension.** If a sketch needs to know where
   the knee is, it projects the knee point.
2. **Left and right are `Symmetric` about the centerline**, never dimensioned separately.
3. **Segments that should match are `Equal`** — thigh to shin, upper arm to forearm.

## Four set-pieces about constraints

The course teaches constraints as a topic. These four make them the lesson: one that builds a
part out of constraints alone, two that diagnose a sketch, and one about choosing where the
sketch lives in the first place.

### 1 — The sloppy quadrilateral

Draw four lines into a closed, deliberately irregular quadrilateral. No care, no aim. Then
square it up with constraints alone:

- **Parallel** — top to bottom, then left to right
- **Perpendicular** — one corner is enough; the parallels carry the other three
- Two **dimensions** — width and height

Four lines and three constraints turn a scribble into a rectangle, and the geometry *moves* as
each one lands. It is the most direct demonstration in the whole course that constraints are
instructions, not annotations.

**It no longer has a part to become.** The result used to be the shin, which is why it was not a
throwaway; at Ø12 the shin is a cylinder. The set-piece is worth keeping on its own merits and it
needs somewhere to land — an open decision, see Stage 5.

> **A naming trap.** Onshape's **Normal** constraint is for a line and a curve, or a curve and
> a plane — not two straight lines. Squaring a quadrilateral is **Perpendicular**. Normal gets
> its honest use where a straight limb meets a curved face.

### 2 — Diagnosing under-constrained: drag it

A blue sketch has freedom left in it. The way to find out *what* freedom is to grab an entity
and pull. Whatever moves is what nothing is holding.

Taught as a habit rather than a fact: before accepting any sketch, drag a corner. If the
sketch is black, nothing moves and the drag costs a second. If something slides, that is the
constraint you have not added yet.

### 3 — Diagnosing over-constrained: interrogate it

When Onshape refuses a constraint, the question is which existing one already says that. Two
moves, both straight from the *Using Constraints* lesson:

- **Click an entity** to see every constraint attached to it.
- **Click a constraint icon** to see which entities it holds.

Tick **Show constraints** in the sketch dialog to see them all at once. Delete a constraint by
selecting its icon and pressing Delete.

Worth engineering deliberately: over-constrain a sketch on purpose — dimension a rectangle's
width, its height, *and* its diagonal — then find and remove the redundant one.

### 4 — Choosing the sketch plane, and diagnosing the wrong one

A sketch lies **in** its plane. Anything brought in with `Use` from somewhere else arrives as
its *shadow* on that plane — projected, not copied. That is not a trap to route around; it is
the rule, and it is learnable in one sentence:

> **Sketch on the face that is parallel to the shape you want to draw, and perpendicular to
> the direction you want to build in.**

The foot's outline is a plan shape, so it belongs on a face parallel to the ground — the
Top plane, or the sole itself. The fork's ears stand off the side of a limb, so they belong on
that side face. Pick the face the shape naturally lies on and the projection is what you
expect; pick a face at an angle to it and you get a foreshortened shadow that is geometrically
correct and not what you meant.

**When someone picks the wrong one**, the symptoms are consistent enough to teach:

| Symptom | What happened |
| --- | --- |
| Projected geometry is shorter than the thing it came from | drawn on a plane at an angle — you have its shadow |
| Two projected points land on top of each other | the plane is edge-on to the line between them |
| The extrude comes out sideways | right shape, wrong plane — extrude follows the normal |
| The sketch is fine but sits in mid-air | a plane was picked where a face was meant |

**The recovery is not to delete the sketch**, and it has two halves — the second is the one
people miss.

1. Open the sketch, clear the **Sketch plane** field with its ✕, and pick the right face. The
   geometry you drew comes with it.
2. **Delete the `Use` projections and re-project them.** They still point at whatever they
   were projected from, so after the plane moves they are the wrong shadows in the right
   sketch. Re-picking the plane does not refresh them.

Constraints attached to a deleted projection go with it, so expect the sketch to turn blue
again and need re-constraining. That is the moment set-piece 2 pays for itself: drag it, see
what moves, put the constraints back.

The symptom that sends people round in circles is *"I fixed the plane and it is still wrong."*
The plane was never the whole problem.

> Reported from experience by the course author rather than tested here — worth reproducing
> once for the screenshots, not for the finding.

### 5 — Construction geometry: when to draw it, and when not to

Construction geometry is drawn but not built: dash-dot on screen, invisible to every feature.
It exists to hold things that guide geometry without being part of it — axes, centerlines,
symmetry lines, a distance worth naming.

**Draw one when nothing else provides what you need.** The clearest case is a **revolve axis**.
A profile can sometimes be revolved about one of its own edges — the half-disc hands do exactly
that — but only when an edge happens to lie on the axis. A profile set away from its axis has
no such edge, and even when there is one, a dedicated axis line survives a change to the
profile that a borrowed edge does not.

**Do not draw one where a real edge already is.** This is where beginners lose time, and the
lesson test measured it: the origin, the two default planes seen edge-on, and a freshly drawn
construction line all sit in the same place and compete for the same click. Onshape will
happily accept a coincident constraint between a line and its own endpoint, glyph and all,
holding nothing. Nothing is wrong with construction geometry there; what is wrong is having two
things in one spot.

So the station heights in this model are edges of real boxes, not construction lines — and the
revolve axes *are* construction lines, because nothing else provides them.

### Fix, and why it is not here

`Fix` grounds an entity so it cannot move. It makes a sketch *look* defined while explaining
nothing about why anything sits where it does, and a student reaching for it is usually
missing a real constraint. Name it, show it, and say when not to use it. The torso is centered
by a **center point rectangle on the origin** — which is what Fix is usually a substitute for.

## The ball and socket joint

Nine of the thirteen joints are the same joint. It is worth building once, properly, and then
copying — so this section is the design, and stage 4 below is only where it lands in the order.

### The move: the socket is the ball, grown by the clearance

Onshape's standalone **Boolean** feature has a **Subtract** operation with an **Offset**, whose
help reads *"Create a gap between the selected faces and remaining parts or surfaces"* — fields
**Offset all**, **Faces to offset**, **Offset distance**, and a **Keep tools** checkbox that
preserves the tool part after the cut.

That turns the joint into three features and **one** sketch:

| # | Feature | What it does |
| - | --- | --- |
| 1 | Sketch the stalk-and-ball half-profile; **Revolve, New** | the ball becomes its own part |
| 2 | **Boolean → Subtract**: Tools = ball, Target = outboard part, **Offset all** = `0.2`, **Keep tools** ✅ | cuts a cavity that *is* the ball plus the clearance |
| 3 | **Boolean → Union**: ball + inboard part | the ball joins the limb it belongs to |

**Order matters.** Union consumes the ball as a separate part, so the subtract has to come
first, and it only survives because **Keep tools** is ticked.

The payoff is that the cavity is **derived from the ball**, not drawn to match it. They cannot
drift apart, because there is only one sphere in the model. The clearance is a single number in
a single field.

### Why not the two obvious alternatives

**Two concentric arcs in one sketch.** The cavity loop completely contains the ball loop, so
Onshape splits them and the cavity stops existing as one selectable region — it becomes the
ball's region plus a crescent 0.2 mm thick, which is not a click target.

**Two sketches, one variable.** Works, but concentricity drops from *structural* to *named*: it
holds only as long as both sketches keep using the same variable. Subtract-with-Offset gets the
structural guarantee back and deletes a sketch.

### The profile

One closed loop, four entities, drawn to the right of the axis:

```
     ┐  ← top of the axis line
     │╲        arc, radius 3, centered on the joint point
     │ ●─ ─ ─  center — the only dimensioned position
     │╱
     ├╯  ← this join is NOT dimensioned
     │        stalk side, 1.5 from the axis
     └──┘
   axis edge — the revolve axis, a real line, not construction geometry
```

Three dimensions: stalk half-width, arc radius, center height. **The point where the stalk
meets the sphere is found by constraint** — the arc's lower endpoint is coincident with the top
of the stalk line, and the solver puts it wherever the current radius says. Change the ball
diameter and the join slides to where it now belongs. That is the whole argument for constraints
in one feature, and it is why this profile is worth teaching rather than just building.

### Numbers

Three of the four are in the Variable Studio and one stays here —
see [the seven the rule brings up with them](#the-seven-the-rule-brings-up-with-them).

| Variable | mm | From | Meaning |
| --- | -- | ---- | --- |
| `#ball` | 12 | `#torsoH / 8` | every ball, all nine joints |
| `#stalk` | 6 | `#ball / 2` | the neck of the ball stud |
| `#fit` | 0.08 | typed; the printer decides this one, like the bar diameter | the gap between the ball and the hollow it turns in |
| `#ballLoss` | 0.10 | typed; what a printed ball loses on its radius | how much narrower than 96 % the mouth is drawn |
| `#grip` | 2.2205 | `sqrt((#ball / 2 + #fit) ^ 2 - (0.48 * #ball - #ballLoss) ^ 2)` | how deep the ball's center sits below the socket's face |

**The mouth is the number that does the work, and grip follows it.** The mouth is drawn at 96 % of
the ball, less twice what a printed ball loses on its radius — **Ø11.32** against a Ø12 ball, so
**0.68 mm of interference** drawn and 0.48 left once the print has taken its 0.10 off each side —
and the ball's depth is whatever puts the cavity sphere through a mouth that size. The socket has
to spread by that interference and it springs back behind the ball. Nothing else needs touching.

**Dimensioned the other way round it breaks when a student edits it.** Hold grip at a number and
let the mouth follow, and loosening `#fit` to 0.8 opens the mouth to 109.8 % of the ball: the
interference goes negative and the ball falls out. Holding the mouth at 96 % survives every value
of `#fit`, and the only thing that moves is how deep the ball sits.
[`experiments/runs/2026-08-25-draft9p1/a2-fit.md`](experiments/runs/2026-08-25-draft9p1/a2-fit.md)
has both readings worked at four fits.

**Grip was typed three times before it was derived.** 2.0 until run 1 built it — at 2.0 the 48 mm
robot's mouth is Ø4.996 against a Ø6 ball, which cannot be pushed in without splitting the collar.
1.35 came back from building it. draft9p0 built 3.6, which is not what doubling 1.35 gives. The
expression above reproduces the joint at any `#ball` and any `#fit` without anyone retyping
anything.

**The check is one measurement.** Measure the circular edge of the mouth: **Ø11.52**. That
single number is only right if the cavity radius *and* its depth are both right.

### Every ball joint sits on a boss

**Decided in discussion, not yet drawn.** A short cylinder at each ball joint, doing two jobs at
once: holding the two parts' broad faces apart, and giving the ball stud somewhere to stand.

**The precondition, which is the whole thing:** a boss only buys tilt **if the face it stands on
steps back**. A pad flush with a broad face changes nothing.

**At the neck it is about tilt.** The head's underside is 36 x 30, so its far corner is 23.4 mm
from the axis, and with a 6 mm gap it hits the torso at asin(6 / 23.4) = **15 deg** — well
before the ball's own limit of about 23 deg. A third of the joint's travel is lost to two flat
plates. Ø12 bosses 4 mm apart move the binding radius to 6 and the limit to **42 deg**, so the
joint becomes limited by the joint. The head's underside must be recessed behind its boss for
any of that to hold. Ø12 also keeps the neck looking exactly as sheet 1 draws it.

**At the ankle it is about the foot.** The shin is Ø12, so its rim swings at radius 6 and tilt
was never the problem. What the boss buys is that the socket mouth lifts clear of the foot
plate, so the plate's thickness, shape and *size* stop being ankle decisions — which is what
lets the feet be as big and goofy as the brief asks for.

**At the hip and shoulder it is the stand-off** that the parts sheet still flags in red.

**Rim chamfers.** Once contact is rim-on-face rather than plate-on-plate, a small area carries
the stop. Chamfer both rims — and the same chamfer at the socket mouth is what would buy tilt
past 23 deg, by letting the stalk lean on a slope instead of a sharp edge.

Open: boss diameter (Ø12 to match the drawn neck, or Ø10), how far each boss protrudes, and
whether the hip boss moves the knee and ankle stations.
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

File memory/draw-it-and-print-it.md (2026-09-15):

---
name: draw-it-and-print-it
description:
  "Never refuse to draw a shape because it might not print as drawn; draw it, print it, and look at
  what came out."
metadata: 
  node_type: memory
  type: feedback
  originSessionId: c7e95b50-7b3c-4747-a656-ece9f33b51c4
  modified: 2026-09-08T14:22:46.836Z
---

Do not gate geometry on a prediction about the printer. If a shape might come out rounded,
bridged or short of the drawing, that is a reason to print it and measure it, not a reason to
draw something else. Nothing prints exactly as drawn, so "it might not print that way" rules out
every shape equally and decides nothing.

**Why:** the user (Mike), 2026-09-08, on refusing to draw pointed wedge crests because a single-bead
tip would not resolve: *"You've been asserting that we can't draw them certain ways because we can't
guarantee they'll print... Let's draw them and print them and see if they work... I would like 15
degree step user experience, more than I'd like controlled mathematical analysis."* The printed
draft9p1p5 joint had already shown the analysis wrong by 2x on leaf tip deflection, so the model was
the weaker evidence and the part was the stronger.

**How to apply:** Draw what the design wants. Say once, plainly, what you expect the printer to do
to it and what to look for in the part; then build it. When a print comes back, measure it and let
the measurement correct the model, as in [[fix-the-model-retake-the-frames]]. Reserve a real
refusal for geometry that cannot exist, not geometry that may come out soft. Related:
[[design-intent-is-not-sacred]], [[write-for-students-who-will-succeed]].

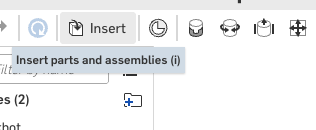
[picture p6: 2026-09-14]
instructions/stickbot-draft9p4/source/images/toolbar/tb-insert.png

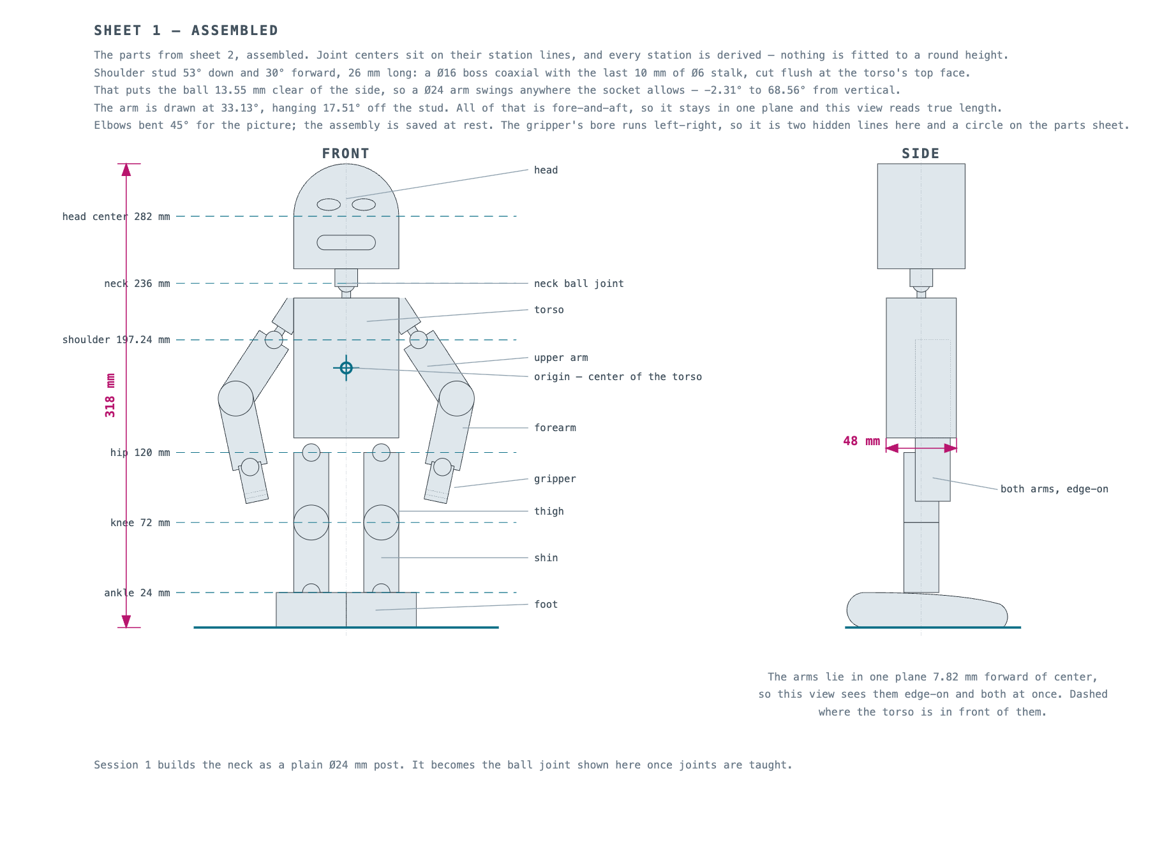
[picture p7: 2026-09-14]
instructions/robot-guide/source/images/plan-assembly.png

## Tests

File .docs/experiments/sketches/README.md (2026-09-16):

# Design sketches

Two kinds of drawing live here. **Explanatory diagrams** — the HTML behind each page published to
claude.ai, where the file is what changes when a number moves, because a published page can be read
but not edited. And **frozen revisions of the initial sketch**, so the plan can be shown changing
under what building it taught.

## A sketch is dated, not current

Each one records the geometry as it stood the day it was drawn, including the reasoning that was
wrong at the time and the correction that followed. The numbers a part is built to live in
[`../build-briefs/`](../build-briefs/). Where a sketch and a brief disagree, the brief is right.

Four carry numbers the design has left behind. Each says so on its own page now, because a
published sketch can be opened by its link without ever passing this table:

- `figure-design-sketch.html` — the concept the project started from: a 150 mm target height, a
  Ø8 limb rod, a Ø6 ball and a 5.0 mouth. The limb is Ø24 and the ball Ø12.
- `socket-study.html` — a Ø16 thigh and `#grip` 1.5, rendered from a model that no longer exists.
- `collar-step-back.html` — the stalk binding "at about 40°". Derived, the limit is 41.76°.
- `hinge-stackup.html` — the fork inside a Ø12 limb, sized before ear and tab were matched on
  section modulus over free length.

## What each one settled

| File | Drawn | What it settled | Published |
| ---- | ----- | --- | --- |
| `figure-design-sketch.html` | 2026-08-10 | Every proportion as a fraction of `#torsoH` 48, and the hand sized to a Ø3.2 LEGO bar | [link](https://claude.ai/code/artifact/45d32957-479f-4ea3-ae5b-5e92fc673ed8) |
| `collar-step-back.html` | 2026-08-11 | That collar height buys swing while limb diameter costs it — why the limb stayed Ø12 | [link](https://claude.ai/code/artifact/6c57b0b2-ce16-45e4-a818-6eb46402c921) |
| `socket-study.html` | 2026-08-11 | Four renders marked up: the sharp mouth rim, the slit root, and a wrong claim that the head's face would block the swing | [link](https://claude.ai/code/artifact/4ca4551b-9045-4679-b0e6-74b1a506c886) |
| `hinge-stackup.html` | 2026-08-11 | The fork drawn as slices of the limb, so no corner stands proud of Ø12 | [link](https://claude.ai/code/artifact/ea2c9509-829d-4466-8b08-a7d4737e7be2) |
| `shoulder-step.html` | 2026-08-11 | The rod-to-blade step narrowing to zero at four points, and the chamfer that gives it a minimum width | [link](https://claude.ai/code/artifact/1c3ec4fb-dd01-4fea-a6a1-d10eea868dca) |
| `hip-clearance.html` | 2026-08-25 | The hip reaching its full ±41.76° with nothing outside the socket in the way, and the collar's rim still 2.554 clear of the torso at that limit | [link](https://claude.ai/code/artifact/5d6520b6-637d-463b-9126-51ba493ae7fa) |
| `socket-wrap.html` | 2026-08-25 | That wrap does not retain the ball — a pure 2× encloses the same 72.5% and still drops it — and that holding the mouth at 96% of the ball retains it while wrapping less, 108.9° against 116.7° | [link](https://claude.ai/code/artifact/6c53133a-de9d-45ca-8dd4-577a54b5e09a) |
| `slit-reach.html` | 2026-08-25 | That the doubled `#slit_in` 5.0 still breaks 0.760 into the mouth, and that the ceiling on `#grip` is 3.459 against the settled 1.9465 | [link](https://claude.ai/code/artifact/20c8d685-0c04-4862-95b9-b7011516d66a) |

**The tab icon each page is published with**, so that republishing one does not turn it into a
different page in a gallery of them: 🦵 `hip-clearance`, 🔵 `socket-wrap`, ✂️ `slit-reach`,
📐 `collar-step-back`, 🔍 `socket-study`, 🔗 `hinge-stackup`. `figure-design-sketch` and
`shoulder-step` have not been republished since theirs were set, so theirs are not recorded here.

## The initial sketch, revision by revision

`src/stickbot/make_plans.py` draws the two plan sheets and writes them over the
previous ones. It draws the current design and only the current design: a generator that can also
draw three superseded revisions is three code paths that have to keep working.

**So freeze the sheets before running it.** Copy both SVGs here under the next revision number,
then regenerate. Miss that and the earlier plan survives only as a diff in the git log, which is
not something a student can be shown beside the new one.

| Revision | Sheets | Generated at | What it depicts |
| --- | --- | --- | --- |
| r1 | `plan-r1-assembly.svg`, `plan-r1-parts.svg` | `624712f` | Height set as a target and the stations fitted to it; arms hanging straight down in both elevations, no shoulder angle in the model at all |
| r2 | `plan-r2-assembly.svg`, `plan-r2-parts.svg` | `3104534` | The shoulder angled and posed, the hinge resized, the height stacked rather than aimed at — 152.65 to the top of the head. Described below |
| r3 | `plan-r3-assembly.svg`, `plan-r3-parts.svg` | `fc8c340` | The head on the standard 5.5 collar, which moved it up: top of head 69.15 and the figure 158.15 |
| r4 | `plan-r4-assembly.svg`, `plan-r4-parts.svg` | `efb314f` | The design at twice the size and the joint left alone, so the figure is 315.4 rather than a doubled 316.3 |
| r5 | `plan-r5-assembly.svg`, `plan-r5-parts.svg` | `6a81d3f` | The blade slit out of the hinge, settled by printing. The blade is solid in both hinge views and the ears carry the whole press fit |
| r6 | `plan-r6-assembly.svg`, `plan-r6-parts.svg` | `0a8a34e` | draft9p1's phase A. The joint dimensioned from the mouth at `#fit` 0.08, so the ball swings ±41.76° and the figure stands 317.05; the eye an ellipse with no pupil; every hinge protrusion on the blade and every recess in the fork; the foot's tread phased off zero and solid at both ends; the head drawn as the arch it is, as wide as the body |
| r7 | `plan-r7-assembly.svg`, `plan-r7-parts.svg` | `edcf145` | draft9p1p1's phase A. The socket measured from the ball's center, so a printing clearance no longer reaches the robot's height and the figure stands 317.00; the relief slit stopped 3.0 below the ball's center so it is a slot for its whole depth rather than a pocket for a third of it; the gripper's clip topped with a flat 18 × 18 platform and necked by a 45° chamfer; the feet centered on their own legs, meeting at x 0 |

Revisions before r1 were overwritten in place and exist only in the history of
`instructions/robot-guide/source/images/`.

r2 is drawn. It carries what run 3 and the geometry audit established: the shoulder stud 53° down
and 30° forward, the hip as a plain stalk after a recess was considered and dropped, and the
joint's own limit on how far it swings. The arms are posed rather than hanging — in one plane
parallel to the front, so the front elevation reads true length with the elbows bent, and the
gripper's bore stays square to that view.

Drawing it moved the shoulder twice. A boss that fat, leaving a vertical face at that angle, traces
an ellipse taller than the room above it — so the first attempt dropped the boss for a plain stalk,
and the second put the boss back and cut it off flush at the torso's top face. Cutting it costs
nothing, and it means the boss can be as fat as it needs to be without the shoulder growing a horn.

The boss is coaxial with the stalk, and that is the part worth remembering. A boss square to the
side face hangs below the ball, so the arm hits it on the way in — worse than no boss at all.
Everything a coaxial boss occupies sits behind the ball, and the socket only ever reaches forward
of it.

The stud also got longer, because the arm is a rod and not a line. With the ball standing the usual
5 mm clear, the Ø12 upper arm fouled the torso through the first 12° of its travel; the sheet said
the joint swings ±37° and the robot could not do it. The stud now runs 13 mm from the side face,
the whole arc is free, and the sheet says what the socket allows rather than what the joint has
left after the body takes its share.

The hinge changed too, and by the same kind of argument. The fork's ears were thin walls that did
not fill the limb; widening them to 4.2 filled it and made them 27 times stiffer, which turned out
to be the wrong 27 times. Ear and blade are springs in series: they carry the same force and split
the movement in inverse proportion to stiffness, so a stiff ear against a thin blade does not share
the work — it takes 0.01 mm of the 0.5 and lets the blade yield alone.

What matters is not thickness but section modulus over free length, because that is what decides
which one yields first. Equal thickness is not equal strength here: the ear is a segment tapering
to nothing at its edges while the tab is a full-width slab. Matched properly, the limb divides four
ways — ear 3.2, tab 2.1, tab 2.1, ear 3.2 — and the movement splits 0.2 and 0.3 at equal stress.

The blade is slit like the socket collar, which is the same trick a second time, and the load path
is what the sizing follows: a joint is only as strong as where the load crosses it, and that is the
tab, not the ear feeding it.

The figure is around 150 mm tall. Height is a consequence of the stations, the stand-off at each
ball and the angle each limb leaves at, so the exact number is whatever `make_plans.py` adds up.
It moved once already, when the hip stalk changed.

## Redrawing one

`hip-clearance.py` writes `hip-clearance.html` into the working directory from the joint's own
numbers. `socket-wrap.py` and `slit-reach.py` each write their page beside themselves from the
inputs of each sizing — ball, stalk, `#fit`, `#grip`, and for the slits a width and two radii —
with every other number and every path point derived. The rest were written by hand.

Republishing an edited file needs that sketch's own URL. Without it the page lands as a second
artifact beside the first, and the table above goes on pointing at the old drawing.

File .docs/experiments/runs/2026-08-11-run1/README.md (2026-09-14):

# Run 1 — 2026-08-11

The first attempt at building the robot's parts with agents. **Frozen.** Nothing here is live;
the models were re-versioned in Onshape before run 2 started, so these links cannot move.

Read this before run 2's results, because most of run 2's briefs exist because of what went
wrong here.

## What was built, and where it is

| Directory | Onshape document | Frozen version |
| --- | --- | --- |
| `ball-and-socket/` | `joint-ball-socket` `dc438a192a01922a9d1ee540` | `run1-archive-2026-08-11` — `5d05ffbe66fa756558cc06b5` |
| `hinge/` | `joint-hinge` `d2f74513ef2f1a7d753a7240` | `run1-archive-2026-08-11` — `c211c28fdabe69ca77a2da49` |
| `lesson-test/` | `lesson-test-4` `c86d7c73e0b468c35d9e86fb` | `run1-archive-2026-08-11` — `380dac31299ddb5f09e565a9` |
| — | `robot-lesson-test-3` `eac50b6ec48f8a12dec5fdac` | `run1-archive-2026-08-11` — `ee0f7823048dc86891dd7fa1` |
| `socket-in-context/` | `socket-in-context` `a60ad741d213d0ee34b573ec` | `run1-archive-2026-08-11` — `fd349d8e2ace5ef92a5a8c81` |

Version link form: `https://cad.onshape.com/documents/<did>/v/<vid>/e/<eid>`.

`socket-in-context` is not an agent build — it is a FeatureScript design study written to show
what the socket looks like added to a head block and to a limb. It also holds the validated
ball-and-socket part, brought in with a **Derived** feature.

## What each run produced, in one line

- **ball-and-socket** — the crux question answered: **Boolean → Subtract with Offset applies
  uniformly over a sphere.** Mouth measured Ø4.99600 against Ø4.996 expected. 147 screenshots.
- **hinge** — stage 1 built and measured on spec; stage 2 teeth on the clevis only. Proved the
  brief's tooth geometry was **impossible as written**, and that Ø12 left only 0.2 mm of clevis
  wall. 43 screenshots.
- **lesson-test** — followed `index.rst` end to end and completed the model, but found that
  **Escape silently discards the last typed dimension** and that four Part-two steps cannot be
  performed as written. 182 screenshots.

## Why run 2 exists

Three things, in order of how much they cost:

1. **The briefs specified geometry that could not exist.** The hinge's teeth overlapped by
   0.9 mm at nominal; the ball socket's `grip` was defined one way and built the other, with an
   acceptance check that passed either way. Both were found by building, not by reading.
2. **Nobody looked at the models.** The reports were numerically perfect and still left the
   wrong shape in the reader's head — the ball socket's relief slits were described as present
   and were, in the agent's own words, "decorative". This produced the **Model inspected** gate
   in the Constitution.
3. **Every agent re-learned the Onshape GUI from nothing**, at 350–525k tokens each. That is
   what [`../../onshape-gui-howto.md`](../../onshape-gui-howto.md) exists to stop.

## What changed between run 1 and run 2

- Limbs **Ø16 → Ø12** (and briefly the other way; see *Why the limbs are Ø12* in the plan).
- Hinge fully respecified: blade 3.0, ears 1.2, fork as **slices of the limb** rather than a
  rectangle inside it, 24 teeth at 15° cut as a wave.
- Ball socket `#grip` **2.0 → 1.35**, giving 0.2 mm of retention interference.
- Every brief now requires a **"Where the work is"** section and a published version.

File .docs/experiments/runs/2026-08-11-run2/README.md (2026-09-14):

# Run 2 — 2026-08-11

The second agent build of the robot's parts, and the first run to work from written briefs
rather than from a conversation. **Frozen.** The three Onshape documents below are published at
named versions; cite those, not the workspaces.

Run 1's results are in [`../2026-08-11-run1/`](../2026-08-11-run1/). Read it first if you want
to know why run 2's briefs say what they say.

## What was built, and where it is

| Directory | Onshape document | Published version |
| --- | --- | --- |
| `ball-and-socket/` | `ball-socket-run2` `b58c15803eb989fe3f676150` | `v1-ball-and-socket` — `278e2c9bf3329c2d7f1244f4` |
| `hinge/` | `hinge-run2` `2348323d25181f7cb2a9aa9b` | `stage-2-detents` — `474270a65596f317b77999cd` |
| `lesson-test/` | `lesson-run2` `ca8494ebddc1d41126fd580e` | `run2-session1-complete` — `24dafb83c2f7814714e20c7e` |

Version link form: `https://cad.onshape.com/documents/<did>/v/<vid>/e/<eid>`. Element ids are in
each directory's `build-notes.md`, under *Where the work is*.

Each directory holds `build-notes.md`, a `steps.log` written one line before and one line after
every action, and the screenshots: 119 for the ball and socket, 255 for the hinge, 204 for the
lesson.

## What run 2 established

- **Boolean → Subtract with Offset applies uniformly over a sphere.** The socket mouth measured
  Ø5.802586 against Ø5.803 predicted. The whole joint design rests on this, and it holds.
- **The slice fork fits.** Both hinge parts measure 12.000 across X and Y, so every layer of the
  fork runs out to the limb's own surface and no corner stands proud.
- **The lesson builds and measures right** — eyes r5.0000, mouth 20.000 overall, neck Ø12.000.
- **Rendering each part alone catches what numbers miss.** The ball-and-socket agent rendered
  the socket on its own and found the relief slits were 2.7 mm deep where the brief said 5.5.
  Every acceptance number had passed.

## What run 2 cost, and what it changed

Six errors in the briefs were found by building them. Most were stale numbers carried from a
superseded revision — a driver changed and the numbers derived from it did not. All six were
corrected **after** this run, so **no build in this directory was made from the current text.**
Run 3 is the first test of it.

Acceptance checks were strengthened in the same pass. A slit came out half depth and every
check still passed, so the briefs now ask for the z-extent of cut faces and the thinnest wall
anywhere in the part, not just the headline dimensions.

The GUI knowledge from these three builds was folded into
[`../../onshape-gui-howto.md`](../../onshape-gui-howto.md), which is what stops the next agent
paying 350–525k tokens to rediscover it.

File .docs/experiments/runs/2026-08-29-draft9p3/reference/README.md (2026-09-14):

# The reference construction

**How `stickbot-draft9p1p1` is built, read off the model itself and off nothing else.** This is what
a take follows and what `audit.part` diffs against, so that a part which reaches the right shape by
the wrong construction is a finding rather than a pass.

The reference is `stickbot-draft9p1p1`, `4b2e0d48efd37d3327a90afb`, workspace
`a1af16872d25103815f1c32a`. It is read only.

## What each file holds

| File | What it is |
| ---- | --- |
| `body.json` | 33 features |
| `head.json` | 26 |
| `ball-and-socket.json` | 14 |
| `foot.json` | 24 |
| `hinge.json` | 49 |
| `u-limb.json` | 10 |
| `l-limb.json` | 10 |
| `gripper.json` | 15 |
| `assembly.json` | 14 instances and 13 mates, with each mate's type and the two instances it joins |
| `variables.json` | the 11 rows of `robot sizes`, with their expressions |
| `documents.json` | the element ids of `stickbot-draft9p3` and `stickbot-draft9p3-check` |

Each Part Studio file carries `order`, the feature tree top to bottom, and `features`, a map from a
feature's name to the `upstream` it was built on and the `downstream` built on it.
[`../../../../tools/read_construction.py`](../../../../tools/read_construction.py) wrote them and
[`../../../../tools/diff_construction.py`](../../../../tools/diff_construction.py) reads two of them
against each other.

## What is in these files, and what is not

**A feature's name, its place in the order, and what it stands on.** That is enough to catch a
boolean operating on the wrong body, a mirror mirroring a loose solid, and a sketch drawn on the
wrong plane, which is four of the four differences found between draft9p2's body tab and this one.

**Not a sketch's constraints, an extrude's end condition, or what a dimension measures from.** Those
live in `/api/partstudios/.../features`, which is rate limited to zero until about 12:30 on
Sat 29 Aug. These files are corrected against that route once it answers, and a take run before then
carries the gap rather than claiming it does not exist.

**Not the mate connectors' names in `assembly.json`.** A mate names its connectors by the Part Studio
feature id that made them, and the id-to-name map comes from the same refused route. The mate names,
the mate types and the instances each mate joins are all recorded.

## What the assembly's order says

Mates were made head, then the left arm shoulder-elbow-wrist, then the right arm elbow-wrist-shoulder,
then the left leg knee-ankle-hip, then the right leg knee-ankle-hip. The second arm and the second leg
each start at the joint furthest from the torso, which is what copying a mated limb and then
attaching it looks like from the outside.

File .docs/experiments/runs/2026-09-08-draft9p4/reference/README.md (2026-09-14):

# The reference construction

**How `stickbot-draft9p1p6` is built, read off the model itself and off nothing else.** draft9p4
teaches this model, so a take follows what is here and the check document is diffed against it. A
part that reaches the right shape by a different construction is a finding, not a pass.

The reference is `stickbot-draft9p1p6`, document `500752af84dc92deea53f9e4`, workspace
`f30bf96cfeece59f61e0e7b2`. Every file here was read at version `80c22eb7b8b0342ac03f8a6d`, which is
the version draft9p1p6's register published. It is read only.

## Why the version and not the workspace

The workspace sits at microversion `1009393f43c6384ece39b921` and the published version at
`dd821b5b9c8498eb568aee67`, so something touched the workspace after the version was cut. All five
tabs' feature lists are identical across the two, which means the bump was not a change to the
model. Reading the version gives a record that cannot move under a later edit, and the register's
numbers describe the same construction.

## What each file holds

| File | What it is |
| ---- | --- |
| `robot-sizes.features.json` | 23 features, all of them variables |
| `variables.json` | the 23 rows of `robot sizes` as Onshape resolves them, with values |
| `ball-and-socket.features.json` | 14 features |
| `ball-and-socket.faces.json` | 22 faces, each with its surface type, radius, axis and area |
| `ball-and-socket.geometry.json` | 3 sketches, with every entity and every constraint |
| `hinge.features.json` | 46 features |
| `hinge.faces.json` | 510 faces |
| `hinge.geometry.json` | 10 sketches |
| `u-limb.features.json` | 9 features |
| `u-limb.faces.json` | 270 faces |
| `u-limb.geometry.json` | 1 sketch |
| `l-limb.features.json` | 9 features |
| `l-limb.faces.json` | 260 faces |
| `l-limb.geometry.json` | 1 sketch |

[`../scripts/p0_read.py`](../scripts/p0_read.py) wrote them. The face files come through
[`../../../../tools/read_shape.py`](../../../../tools/read_shape.py) and the geometry files through
[`../../../../tools/read_sketches.py`](../../../../tools/read_sketches.py).

## What is in these files that draft9p3's record did not have

draft9p3 recorded each feature's name, its place in the order, and what it was built on. This record
carries that and three things more.

- **Every parameter of every feature, with its expression.** An extrude's end condition, its second
  direction, and the variable its depth names.
- **Every sketch entity and every constraint.** `blade profile` is 4 entities held by 11 constraints,
  and the record says which 11.
- **Every face of every part.** Surface type, radius, axis and area, which is what proves a shape
  without trusting a feature name.

## What a feature stores that it is not using

Onshape keeps a value on every parameter a feature could have, switched on or not. An extrude that is
neither drafted nor offset still carries `draftAngle 3 deg`, `offsetDistance 25 mm` and
`secondDirectionDepth 25 mm`. A transform that moves a part to a mate connector still carries
`distance 25 mm` and `angle 30 deg` from the translate and rotate options it is not using. Reading
those as though a builder typed them buries the numbers a builder did type.

The switch that matters is beside the value. An extrude's depth is live when `endBound` is `BLIND`; a
revolve's angle is dead when `fullRevolve` is true; a transform's distance is live only when
`transformType` is `TRANSLATION_DISTANCE`.

A sketch dimension is the same story. Its value is the `length` or `angle` parameter.
`labelRatio` and `labelAngle` place the label on the screen, in radians and meters, and are not the
dimension.

[`../scripts/typed_numbers.py`](../scripts/typed_numbers.py) reads the record through those switches
and prints the two tables below.

## Where draft9p1p6 types a number

Twenty-four numbers in the whole reference are typed. Everything else is derived from one of them.

**`robot sizes`, 11 typed of 23 rows.**

| Row | Value |
| --- | ----- |
| `#torsoH` | 96 mm |
| `#torsoW` | 72 mm |
| `#torsoD` | 48 mm |
| `#limbCenter` | 48 mm |
| `#fit` | 0.08 mm |
| `#ballLoss` | 0.10 mm |
| `#t_print` | 0.10 mm |
| `#blade` | 10 mm |
| `#wedge_h` | 0.75 mm |
| `#wedge_c` | 0.15 mm |
| `#blade_out` | 32 mm |

**`ball and socket`, 1 typed.** `#slit` at 1.6 mm.

**`hinge`, 12 typed.**

| Feature | What is typed |
| --- | --- |
| `#stub` | 4 mm |
| `#leaf_root` | 4.20 mm |
| `#leaf_tip` | 1.50 mm |
| `#wedges` | 24 |
| `#ring_in` | 6.00 mm |
| `blade wedge` | draft angle 45 deg |
| `blade wedges` | pattern angle 360 deg |
| `fork blade top cut outline` | three dimensions at 2 mm |
| `ear wedge` | draft angle 45 deg |
| `ear wedges` | pattern angle 360 deg |

**`u limb` and `l limb`, none.** Both tabs derive every number they use, and their one sketch each is
fully driven.

## Numbers typed inside an expression that otherwise derives

A ratio is how one size is built from another. A length added to a variable is a typed size wearing
an expression, and it is worth seeing in the same list.

| Tab | Row | Expression |
| --- | --- | --- |
| `robot sizes` | `#grip` | `sqrt((#ball / 2 + #fit) ^ 2 - (0.48 * #ball - #ballLoss) ^ 2)` |
| `robot sizes` | `#slot_deep` | `#blade_out + 1 mm` |
| `hinge` | `#stub_proud` | `2 * #wedge_h + 1.50 mm` |
| `hinge` | `#bore_d` | `#stub + 0.1 mm` |

Two more rows match the same search and are not the same thing. `#wedge_eps` ends in `* 1 rad`,
which converts a ratio into an angle, and `#wedge_w` starts from `180 deg / #wedges`, which is a half
turn shared out. Neither is a size somebody chose.

## The two variable naming conventions in `hinge`

A variable is a feature, so it has a feature name as well as a variable name. Onshape's default
feature name for one is the literal string `###name = #value`. Renaming the feature to the variable's
own name makes the tree readable; leaving it makes eight rows in a row that all read alike.

`hinge` does both, and this is how it stands:

- **Renamed, 8 rows.** `#nose`, `#ear`, `#stub`, `#stub_proud`, `#bore_d`, `#slit_h`, `#rod_blade`,
  `#rod_fork`.
- **Left at the default, 10 rows.** `#leaf_root`, `#leaf_tip`, `#wedges`, `#ring_in`, `#ring_out`,
  `#wedge_bind`, `#wedge_inset`, `#wedge_eps`, `#wedge_w`, `#backlash`.

The split follows the drafts. The renamed eight came in at draft9p1p4 or earlier; the ten defaults
are the wedge ring, added at draft9p1p5 and draft9p1p6.

`ball and socket` renames all 5 of its rows. `robot sizes` leaves all 23 at the default, where the
Variable Studio shows the variable name in its own column and the feature name never shows.

This is recorded as it is. Which convention draft9p4 teaches is a question for the plan, not
something to settle by tidying the reference.

## What the feature trees hold

| Tab | Features | Types |
| --- | --- | ----- |
| `robot sizes` | 23 | 23 variables |
| `ball and socket` | 14 | 5 variables, 3 sketches, 2 extrudes, 2 mate connectors, 1 revolve, 1 boolean |
| `hinge` | 46 | 18 variables, 10 sketches, 10 extrudes, 3 mate connectors, 2 circular patterns, 2 mirrors, 1 boolean |
| `u limb` | 9 | 3 mate connectors, 2 derives, 1 sketch, 1 extrude, 1 transform, 1 boolean |
| `l limb` | 9 | 3 mate connectors, 2 derives, 1 sketch, 1 extrude, 1 transform, 1 boolean |

`hinge`'s ten sketches, in tree order: `blade profile`, `stub axle outline`, `blade wedge outline`,
`blade rod outline`, `relief slit outline`, `fork outline`, `fork blade top cut outline`,
`pocket axle sketch`, `ear wedge outline`, `fork arm outline`.

`ball and socket`'s three: `stud profile`, `collar profile`, `slit profile`.

Both limbs have one sketch each, `limb section`, and both reach their shape by deriving the joint
parts and transforming them onto mate connectors rather than by drawing them again.

## What this record does not cover

**The five tabs draft9p4 also teaches that draft9p1p6 does not have.** `body`, `head`, `foot`,
`gripper` and the assembly are not in this document. Their reference is draft9p1p1, recorded at
[`../../2026-08-29-draft9p3/reference/`](../../2026-08-29-draft9p3/reference/), and what draft9p3
built on top of it. A take of tutorials 1, 2, 3, 5, 6, 7, 8 and 12 reads there.

**The assembly.** draft9p1p6 has no assembly tab.

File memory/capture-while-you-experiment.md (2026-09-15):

---
name: capture-while-you-experiment
description:
  "Take the named frames on the first pass through a click sequence, not on a second pass; a
  debugging screenshot is not a frame, and attempting the shot is how tooling gaps surface"
metadata:
  type: feedback
---

**Capture while working out the click sequence, not afterwards.** Do not split the work into
*figure out the sequence*, then *do it again with capture*. Every place a `page.screenshot`
happens for debugging is a place a named frame belongs — `gui.frame(page, path)` is one line, and
the expensive part (driving the browser into the right state) has already been paid for.

**Why:** on 2026-08-20 tutorial 1 was built with 17 scratchpad screenshots and **zero** frames.
The screenshots were named `dim1.png`, `state.png`, `extrude3.png` — framed for reading, not for use
on a page. Attempting the planned shots would have caught
two plan defects at the moment they happened: the *version dialog* shot is unreachable when the
version is published by a REST call, and the *insert into all, off* shot does not exist because
the control arrives already ticked.

**How to apply:** the shot plan exists so the shots get taken. Name the frame by its step
identifier at the moment the state is on screen. Trying the shot is itself the test of the capture
tooling. Holding the step and its frames in mind at once costs context, and the user would rather
raise the context limit than get a second pass.

Related: [[every-feature-gets-its-name]], [[write-for-students-who-will-succeed]].

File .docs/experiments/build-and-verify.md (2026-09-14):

# The build-and-verify cycle

**Superseded by [`../build/takes.md`](../build/takes.md).** This cycle runs waves of
subagents building parts from briefs; CAD is no longer handed to a subagent. The rules of it
that are still in force were carried into the retake procedure and are stated there. What is
here is history.

The loop that turns a written brief into a built, measured part — and into a corrected brief.
One pass through it is a **wave**. The robot is finished by running waves until every part
exists, then one more wave for the assembly.

This file is the procedure. It does not restate the checks:
[`../2026-08-12-launch-gate.md`](../2026-08-12-launch-gate.md) is what the launcher performs
before and after each wave, [`build-briefs/README.md`](build-briefs/README.md) is what the
agents are held to, and [`run3-launch.md`](run3-launch.md) is a worked example of a launch —
reading list, prompt tails, document names, watchdog cadence.

## Starting one

What the user says:

> Run the build-and-verify cycle for `<parts>`. Hold between waves.

Everything else has a default, and the default is stated here so it does not have to be
negotiated each time.

| Knob | Default if unsaid |
| ---- | --- |
| which parts are in the wave | parts that do not depend on each other, as many as fit the clock |
| between waves | report and hold; the user launches the next one |
| retries | one, against a corrected brief, then report and stop |
| a brief that fails twice | stop and ask — see *When to stop* |
| the assembly | never in the same wave as a part it assembles |

"Hold between waves" is the safe reading and the one to say out loud. Without it the next wave
launches on the previous wave's results without the user seeing them.

### Running it unattended

What the user says when they are going to bed:

> Run the cycle for `<parts>` without me.

Three things change, and they should be said back before starting:

- **No holding between waves.** A wave launches as soon as its dependencies are met, which is
  not the same as waiting for the previous wave to finish. A part whose brief depends only on a
  joint that is already built and corrected can start immediately; only the assembly genuinely
  waits for everything.
- **"Stop and ask" becomes "park and continue."** Every decision that would have been a question
  goes into one file with what is known and what it turns on, and the work goes on around it.
  Nothing is decided on the user's behalf, and nothing is left un-built because a decision is
  pending — those are different things.
- **Commit, do not push.** The Branch Policy already says push only when asked, and being asleep
  is not asking.

**What still stops everything**: a finding that means the geometry does not exist. Everything
else runs. See *Waves*.

## One wave

**Gate the briefs, together, and write down what the gate turned up.** Per the launch gate. All
of the wave's briefs are gated before any of the wave's agents start, because a correction made
after launch does not reach an agent that has already read the file.

**Freeze the text.** From launch until the last agent reports, the briefs and
`build-briefs/README.md` are not edited. Findings are collected and applied afterwards. This is
the rule that run 3's first attempt broke.

**Launch the wave together**, each agent in its own new Onshape document, named for the part and
the run. Record every agent's id in the run directory as it starts — the id is the only way to
interview a finished agent, and it does not outlive the launching session.

**Watchdog.** Poll each agent's `steps.log`; a log that has not moved is not proof of death, so
ping before killing. `run3-launch.md` carries the cadence and the grace period, both set by what
went wrong before.

**A watchdog that reads file age is blind across a handover.** When a replacement agent takes
over a dead one's document, it inherits the dead agent's `steps.log`, and the file's age keeps
counting from the *predecessor's* last write. The log looks hours stale while the new agent is
working normally through its reading list — which is long, because a replacement is given the
predecessor's notes on top of the usual briefs. Run 3 raised this false alarm on every handover.

The fix belongs in the prompt, not the watchdog: **tell a replacement agent to append a handover
line to `steps.log` as its first action, before it reads anything.** One line, and file age
starts telling the truth again.

**Verify each part yourself, before reading anything the agent wrote.** Open it at its published
version, turn it, take the measurements the brief asks for. Reading the report first tells you
what to expect and you will see it. This ordering is the point of the whole step.

**Then say what the part does next, and what would stop it.** The measurements a brief asks for
are that brief's own idea of what can go wrong, so a part can satisfy every one of them and still
be unusable. For a robot part the next thing is a mate: name it, then name what would prevent it —
nothing retaining the ball, no swing, a face that binds first. This is the last question answered
before a part is accepted, and every brief's acceptance checks carry it. Run 3's head passed every
measurement in its brief with a socket no ball can enter, no relief slits, and a 1 mm collar
against a specified 5.5.

**Interview each agent.** A retrospective, not a cross-examination — the launch gate says what to
ask and why. The agent is the only witness to where the brief failed it.

**Fold the findings into the briefs.** Into the brief, not only into the run's notes. A finding
that lives in a build-notes file is a finding the next agent will not read. If a number moved,
change the generator that draws it, not the prose about it.

**Then decide: accept, retry, or stop.**

## Retries

A retry is a fresh agent, against the corrected brief, in a **new empty document**. Never reopen
the failed one. A half-built document hides the thing the retry exists to test — whether the
corrected brief gets someone from nothing to the part.

What changes between attempts is the **brief**. If nothing about the brief changed, the retry is
the same experiment and will teach the same thing.

Name the retry's document for the attempt, so the failed one stays inspectable rather than being
overwritten.

## Waves

**Parts first, in any order that respects their dependencies.** A joint is a part. Two parts that
share no numbers can be built in the same wave by different agents.

**Every part of this robot carries a joint**, so every part wave inherits whatever the joint
waves found. What it inherits is only the numbers, though — see below.

**Only a finding that stops the geometry existing blocks the next wave.** A number that moved, a
feature that cannot be built, a face that comes out square when the brief says round: let one of
those through and it is embedded in every part built afterwards. A finding that means the joint
will not *work* — the detent will not click, the socket will not retain, a wall is too thin to
survive a print — does not block anything. The part still models, still mates, still assembles;
only the printed plastic cares. Carry it forward and mark it not print-ready.

Mike's framing, 2026-08-12: *"push forward with imperfect joints, because you can make all of
the body parts, you can even mate them, the broken joints just won't work in the physical 3d
printed world."* Waiting for a joint to be perfect stalls eight parts on a defect a printer
finds and a CAD model does not.

**The assembly is its own wave**, and it cannot start until every part it uses has been built and
published as a named version. Built, not sound — a robot assembled from parts that will not print
still proves the mates and the degrees of freedom. It differs from a part wave in what gets
verified: mates and degrees of freedom rather than extents and wall thicknesses, and whether the
robot moves the way the plan says rather than whether a face measures what it should.

**A wave is most of a session.** The Constitution's clock applies to the launcher too — the gate,
the watchdog, the verification and the interviews are all hands-on time, and they run longer than
the building does.

## When to stop and ask

- **A brief fails twice for different reasons.** Once is a brief defect. Twice, in two places,
  usually means the design is wrong rather than the words describing it, and that is the user's
  call and not a thing to iterate on.
- **A finding contradicts a settled decision.** Settled means decided in conversation and
  recorded. An agent hitting one is a reason to check the record, not to reopen it — run 3's
  first attempt was thrown out for launching against a conflict that had been settled the day
  before.
- **The measurement disagrees with the report and the agent cannot say why.** Something happened
  that neither of you understands yet.

**Unattended, every one of these is parked rather than asked**, in a single file the user reads
in the morning: what was found, what it turns on, what the options cost, and — where there is
one — the cheap answer. A parked decision that stops a part being built is a decision made by
default, so build to the number as written, measure, and report the gap.

**One thing is never parked: an agent breaking a standing rule.** Run 3's hinge agent reached
into port 9222 to recover the shared Onshape session after it signed out for every agent at
once. It reported it at the top of its notes rather than burying it, which is what the contract
asks for, and it goes at the top of the parked file too — not among the design questions.

## What ends the cycle

Every part built, measured and published at a named version; the assembly built from those
versions and moving; and every brief carrying what its run found. What is left after that is the
lesson, which is tested by a different loop — a student following the written steps from an empty
document, not an agent following a brief.

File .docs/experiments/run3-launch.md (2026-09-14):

# Run 3 — the launch prompts

The text each agent is given, recorded here so it can be read, criticized and reused. Run 1 and
run 2's prompts existed only inside a session log.

Run 3 is the first build from the corrected briefs. Every brief and the lesson were corrected
after run 2 built from them, so nothing here has been tested as written.

Perform [`../2026-08-12-launch-gate.md`](../2026-08-12-launch-gate.md) before launching, and
write what it turned up to `runs/2026-08-12-run3/gate.md`.

## The attempt that was thrown out

Run 3 was launched once on 2026-08-12 and stopped. The three agents read a
[`build-briefs/README.md`](build-briefs/README.md) that claimed an open conflict over limb
sections; there was no such conflict, `#limbD` having been settled at 12 the previous day. The
Onshape documents `ball-socket-run3` and `lesson-run3` are deleted, and only `hinge-run3` was
ever named. Nothing from it was published or cited.

## What changed in the prompts
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

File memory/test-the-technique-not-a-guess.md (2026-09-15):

---
name: test-the-technique-not-a-guess
description:
  "Before reporting that a technique does not work, confirm the run actually performed it as
  specified."
metadata:
  type: feedback
---

The user (Mike) gave me the Shift trick for mate connectors; I built a spike that pressed Shift
*before* hovering, found nothing changed, and wrote up "Shift is not what does the work" in the
notes, the howto and a plan file. Shift locks the reference to the face **already** hovered, so
pressing it first locks nothing. The order was the technique and I had inverted it.

**Why:** a negative result about somebody's method is a claim about their method, and it gets
copied into permanent files. Mine was a claim about a sequence nobody uses.
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

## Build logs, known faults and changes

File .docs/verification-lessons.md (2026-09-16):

# Verification — what actually catches failures

This session produced a clean worked example of reporting success that wasn't there. The model was
declared complete and correct while it was missing its legs and one hand. Recording how, because
the failure mode is general and cheap to repeat.

## The incident

The taught-path model was built, every feature reported `OK` on creation, a render was inspected,
and the work was reported as done. Two of the 22 features were in fact in `ERROR` —
`Extrude 2` (legs) and `Revolve 1` (right hand), both "No merge scope selected." It surfaced only
because the user asked, directly, whether every step had actually succeeded.

Three independent mistakes had to line up:

1. **The creation-time status was stale.** Each `POST` returned `featureStatus: OK`. The features
   broke later, on a regeneration triggered by an unrelated part-metadata write. *Green when
   created is not green now.*
2. **The verification tool was broken and the breakage was ignored.** `featureStates` is an **array
   of `{key, value}` pairs**, not a map. Indexing it as a map printed `?` for all 22 features. The
   correct response was to fix the check; instead the earlier creation-time results were reported
   in its place. That is precisely the "never claim a verification you did not perform" rule.
3. **The render was misread.** The right arm ending in a flat stub and the shoes floating with no
   legs connecting them were both plainly visible in an image that had been looked at and called
   correct.

The renders were not lying. Nobody was reading them adversarially.

## Checks that work

- **Re-read state from the server after every mutation, including unrelated ones.** Metadata writes
  trigger regeneration and can break geometry features.
- **Tally, don't skim.** Print `{"OK": 22}` — a count that must equal the feature count. A wall of
  mostly-`OK` lines hides two `ERROR`s; a tally cannot.
- **Treat a `?` or `MISSING` in your own output as a failure**, never as a cosmetic wart. It means
  the check is not checking.
- **Confirm geometry independently of status codes.** Bounding boxes are cheap and decisive: the
  body spanning `z = 1 → 13` proves legs exist; `x = ±9.3` proves both hands exist. A status code
  says a feature regenerated; a bounding box says the shape is right.
- **Look at the render with a specific question.** Not "does this look right" but "count the
  hands; trace the legs from body to shoe". Open-ended looking confirms what you expect.

## What status codes do not tell you

`featureStatus` reports **regeneration success only**.

- `INFO` covers real defects. A `Remove` extrude that cut empty air reported `INFO`, and the model
  was visibly wrong while the tree looked healthy.
- "Not fully defined" does **not** appear in `featureStatus`. All ten sketches in the reference
  model have no constraints whatsoever and every one reports `OK`. That gap is invisible to this
  check — see [`modeling-practice`](../.claude/skills/modeling-practice/SKILL.md).

So a green tree means "it rebuilt", not "it is correct" and certainly not "it is well built". Three
separate gates, and only the first is automated.

## Looking at pictures: what it caught, and what it invented

Generating the guide meant looking hard at forty screenshots of the real UI. That is a powerful
check and a powerful way to be confidently wrong, and both showed up in one session.

**What it caught — the best find in the project so far.** Step 20's instruction said to tick
**Direction** to flip the grin's cut. The photographed dialog shows the flip is the small arrow
button beside the end-condition dropdown; Direction is a separate checkbox that does something
else. That error had survived being written down, reviewed, and copied into two files. A room of
students would have ticked the wrong control and still had no grin. No amount of status-code
checking would have found it — only a picture of the actual dialog.

**What it invented — three wrong diagnoses, all from reading a picture too eagerly.**

1. "The tree says 26 features on a 22-feature model, so something is duplicating features."
   Onshape counts the four default datums in that total. 26 *is* 22.
2. "The shoes are different colors, so last run's appearance metadata is leaking." The metadata
   said otherwise: every part in a fresh build is marked generated, and Onshape gives different
   parts different defaults. A student sees the same thing.
3. "Two dimensions make the rectangle fully defined." They do not — the shape is fixed but it can
   still slide. The screenshot showed it still blue while the prose said otherwise.

The pattern in all three: a picture showed something surprising, a plausible cause arrived
immediately, and it reached prose or a commit message before anything was measured. The surprising
thing was real every time; the explanation was wrong every time.

**The rule that follows.** A picture is evidence that something is *worth investigating*, never
evidence of *why*. Each of the three above was one API call away from being answered instead of
guessed. Screenshots earn their place as the thing that notices; measurements stay the thing that
concludes.

## Bearing on the course

Two of these are student-facing and belong in the step files:

- **A feature can be green when created and red on a later rebuild.** A student who adds the legs,
  moves on, and returns to a red feature will assume they broke it just now. Say so in advance.
- **Onshape does not always error when something goes wrong.** The smile that removes nothing is an
  `INFO`. Teach the habit of looking at the model, not just the feature tree — which is the same
  habit this section is about.

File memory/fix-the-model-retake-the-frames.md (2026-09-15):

---
name: fix-the-model-retake-the-frames
description:
  "Fixing a model obsoletes every frame that shows the old state; retake them, never write around
  them."
metadata: 
  node_type: memory
  type: feedback
  originSessionId: c7e95b50-7b3c-4747-a656-ece9f33b51c4
  modified: 2026-08-30T01:48:09.904Z
---

When a fix changes what the model looks like, the frames of the old state are wrong and MUST be
retaken. Do not write the page around them, and do not offer that as an option.

**Why:** a page is written from its frames. A frame showing a state the model no longer has teaches
the reader something untrue, and the caption usually asserts it out loud — tutorial 8's
`pedestal_sketch-05` says "black because the sketch is now fully defined" over a picture of an
under-defined sketch. Leaving it turns one model defect into a permanent page defect.

**How to apply:** the moment a fix lands, list every frame of every step the fix touches and drive
those steps again. Retaking is part of the fix, not a follow-up task. Keep pushing until the frames
and the model agree.

See [[capture-while-you-experiment]], [[design-intent-is-not-sacred]] and
[[write-for-students-who-will-succeed]].

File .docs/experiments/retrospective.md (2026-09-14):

# Retrospective — what the agent runs have taught, across runs 1 and 2

**Synthesized, not interviewed.** An agent that has finished cannot be reached — `ListAgents`
returns empty — so runs 1 and 2 could only be read back out of what they wrote. Everything below
is quoted or drawn from the six `build-notes.md` and `report.md` files under
[`runs/`](runs/). From run 3 onward a retrospective is a required deliverable, written by the
agent about its own run, so the next version of this file will have first-hand answers in it.

That gap is itself the first finding: **whatever you want from an agent has to be asked for
before it starts.**

## What went well

- **Rendering each part on its own caught what every number missed.** Twice. The ball-and-socket
  agent rendered the socket alone and found relief slits 2.7 mm deep against 5.5 specified,
  after every acceptance number had passed. The hinge agent found the entire fork invisible in
  all four standard whole-model views, because the parts overlapped along the camera axis — the
  joint had never actually been looked at. This is now a rule in every brief.
- **One crux question, answered decisively.** Both joint briefs named a single measurement that
  would settle the design. Subtract-with-Offset applies uniformly over a sphere: mouth measured
  Ø5.802586 against Ø5.803. The question was worth more than the part.
- **`steps.log` made slow distinguishable from dead.** An "about to" line before each action and
  a "result" line after is what let a quiet agent be pinged instead of killed — which saved a
  live build in run 2.
- **The how-to stopped the re-learning tax.** Every run-1 agent rediscovered the Onshape GUI
  from nothing, at 350–525k tokens each. Run 2's agents read
  [`../onshape-gui-howto.md`](../onshape-gui-howto.md) instead.
- **Measurement routes were named, not just results.** "FS `evSurfaceDefinition`", "off
  Onshape's own bottom-right readout, photographed". A number whose provenance is stated can be
  disbelieved; one without cannot.

## What went poorly

- **Stale numbers survived a driver change.** Six brief errors in run 2 alone, and almost all
  were the same failure: a driving dimension moved and the numbers derived from it did not.
- **Acceptance checks passed on wrong parts.** The half-depth slit passed every headline
  dimension. A socket built upside down measures the same mouth as a correct one — 2 × √(3.2² −
  1.35²) either way — and is distinguished only by cavity volume, 109.48 mm³ against 27.78.
- **Direction errors were caught by volume, not by preview.** The hinge agent built, checked,
  found wrong and rebuilt four features — the stub twice, once as a 226 mm circle and once
  pointing into the ear — and reported that "all three direction errors were caught by volume,
  not by looking at the preview."
- **The modeling standard was not followed, and the agent said why.** The hinge model has no
  variables at all: 6.11 typed in four places, 12 in two. Its notes say variables have to
  precede the features that use them, and it realized too late to re-roll the tree safely.
- **Timings mean nothing and keep being collected.** One run reports 82 minutes, another
  "several hours", and both say the same thing about it: the cost was not modeling, it was that
  every dialog field had to be picked by coordinate and verified by screenshot. Agent pace is
  not student pace and never will be.
- **The same gate has been unmet three runs running.** No link has ever been checked from a
  student-level account. Every report says so honestly, and nothing changes, because no agent
  can fix it.
- **Ambiguous phrasing cost a guess.** "About 10 wide and 10 tall", of a profile drawn to one
  side of a revolve axis, could mean Ø10 or Ø20. The agent picked Ø10 and said so.

## What to change

1. **When a driver moves, recompute everything downstream in the same edit.** This is the single
   largest source of error across both runs. It is a rule about editing, not about CAD.
2. **Every acceptance check must be able to fail on the specific wrong part it guards.** If a
   check passes on both the right build and the failure it was written for, it is not a check.
   The cavity-volume and slit-z-extent checks exist because of this and both now appear in every
   brief that has a socket.
3. **Put variables in a Variable Studio**, so ordering stops mattering and a model can be given
   its variables after the fact. The hinge agent's own recommendation.
4. **Stop asking for timings that cannot mean anything.** Ask for the *shape* of where the time
   went — which steps dominated and why — and say in the prompt that a student estimate is not
   wanted. The clock gate has to be met by a person walking the steps.
5. **Give a diameter or a half-width, never a width.** A brief describing a revolve profile must
   say which side of the axis it means.
6. **Ask for the retrospective up front.** Applied from run 3.
7. **One person needs to open the links from a student account, once.** No agent can close this
   gate, and it has now been carried as an open item through three runs.

## Still open after two runs

- Nothing has been **printed**. Every fit — the snap, the detent, the 0.197 mm of retention — is
  a number that survived being modeled, not one that survived being used.
- The *Steps reproduce* gate is unmet for both joints. Neither was rebuilt from an empty
  document following only the written steps; run 3 is the first attempt at that.
- The lesson does not fit the clock: 82 minutes at agent pace against a 90-minute budget, with
  Part two 1.7× Part one.

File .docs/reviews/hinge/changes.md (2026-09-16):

# Changes Mike wants to the hinge review

Running notes, taken while Mike reads `index.rst`. His words are the record; anything I add is
marked *(mine)*. Nothing here has been applied to `index.rst`, the figures, `make_plans.py` or
the CAD.

## Subtract

### One Part Studio holding two parts is not a problem

> "It is good that the hinge is a part studio that makes two parts. the two sides of the hinge
> work together and are designed from each other, putting them in one part studio defines that
> relationship and allows one to be easily made from the other. Being two parts in one studio is
> not a problem."

*(mine)* Where this lands in the review: the section *Both parts are still called Part 1 and Part 2*
(line 215) is about the two default names, not about the studio holding two parts, so the finding
itself survives. What has to change is anything that reads as if the arrangement were the
complaint, and the section should say plainly that one studio holding both halves is the right
arrangement and why — the two sides are designed from each other.

### A heading under this title reads as a charge, even when it reports good news

> "Reading your **bolded** text: 'What is wrong with the hinge' and 'Both documents hold the same
> joint' implies a claim that this is wrong."

*(mine)* The two documents agreeing is the good outcome, and the section's own body says so — it is
there to scope the review, not to accuse. The title makes every ``==`` heading beneath it read as an
item in the charge sheet, so a section that reports a fact or good news has to say that in the
heading itself, or the document needs a structure that separates what is wrong from what was
checked and found sound.

The same problem, not yet raised by Mike: *But the limb's rod buries the excess, so the printed
joint is right* (line 73) is also a not-wrong finding, and its heading opens with "But", which reads
as a continuation of the charge rather than a correction of it.

## Add

### The ear's valleys break out through the side of the fork

> "The ear valleys extend past the outside of the fork, we need to either have the valleys go all
> the way through the fork, or provide 1mm of thickness margin at outside of the fork so that the
> outside of the fork has a minimum thickness."

*(mine)* Checked against the numbers. The ear is a slice of the Ø``LIMB`` 24 cylinder, so it is
``EAR`` 6.4 thick only on the limb's axis and thins to nothing at the flank: at ``y`` from that axis
it is ``sqrt(12**2 - y**2) - SLOT/2``. The detent band sits at ``BUMP_R`` 9.60 with ``VALLEY_D`` 2.0
holes ``VALLEY_DEEP`` 0.90 deep, so a valley's outer edge reaches ``y`` 10.6, where the ear is
**0.025 mm** thick. It is not close: the hole is out through the flank.

| tooth | valley's outer edge | ear there | left under the valley |
| --- | --- | --- | --- |
| 0 deg | 10.600 | 0.025 | -0.875 |
| 15 deg | 10.273 | 0.602 | -0.298 |
| 30 deg | 9.314 | 1.967 | +1.067 |

``STEP`` is 15 deg, so 24 teeth, and six of them break out: 0, 15, 165, 180, 195 and 345 deg. The
two on the axis are the worst.

What each of Mike's two options costs, as far as arithmetic can say:

- **Through.** The valley becomes a hole, and at those six teeth it opens as a scallop in the limb's
  outside surface, not a round hole. The detent still works; the flank stops being smooth.
- **A 1 mm floor.** A valley may then reach out to ``y`` 9.367, so ``BUMP_R`` has to come in from
  9.60 to **8.367 or less**, and the band from 8.80 .. 10.40 to about 7.57 .. 9.17. The bore is
  R 2.2, so the band's inner edge cannot go below 3.20 without cutting into it; there is room. A
  smaller ``BUMP_R`` is a shorter lever arm, so the same bump gives less holding torque.

This also touches ``detail_hinge``'s right-hand view, which draws the band square on and would show
the break-out if it drew the ear's outline; it draws only the chord.

### The blade's bottom connector is not on the bottom of the blade

> "The mate connector for the bottom of the bade is not on the bottom of the blade."

*(mine)* Already on the page, as *draft9p3's blade connector landed on the tongue's root step*
(line 200), and open as task #142. Mike raising it independently is a confirmation, not a new
finding, so it needs no new section. The measurements it rests on: ``stickbot-draft9p1p1`` puts
``blade to robot connector`` at ``(0, 0, -26.4)``, on the blade's end face and on the limb axis;
``stickbot-draft9p3`` puts it at ``(0, -7.884, -20)``, the centroid of the step where the tongue
meets its own limb, 7.884 off the axis and 6.4 short of the end face.

What the review does not yet say, and Mike's wording points at: the connector is *named* for the
bottom of the blade, so the name and the place disagree, and that is what makes it a defect rather
than a choice. The section calls it a build defect belonging to draft9p3 alone; that still holds.

Sharpened by Mike:

> "The blade to robot connector is not in the center of the bottom of the blade."

*(mine)* So it is two independent errors, not one, and the fix has to name both: it is on the wrong
face, and it is not centered on the face it is on. Moving it to the end face without saying
*centered* would leave the second one. Its ``y`` of -7.884 is the centroid of the step face, whose
box is ``[-10.909, -12, -20] .. [10.909, -5, -20]`` — a segment of the Ø24 circle, not a full disc,
so its centroid is off the axis. That is the same failure as task #118, where ``socket connect to
robot`` inferred CENTROID where CENTER was wanted; picking a face and letting Onshape infer the
point is what produces it both times.

### The fork's connector is not on the top of the fork either

> "The fork to robot connector is not on the top of the fork, and not centered on the top of the
> fork."

*(mine)* The height half is measured and on the page already, as *The two robot connectors are
placed by two different rules* (line 176) and task #141: ``fork to robot connector`` reads back at
``(0, 0, 12)`` in both documents, which is ``NOSE`` from the pin and 15.4 mm short of the fork's own
end face at ``z`` +27.4, so it sits inside the material.

The centering half does not match what I measured, and I would rather say so than write it down
wrong. At ``(0, 0, 12)`` it is on the limb axis, so it is centered across the fork; what it is not
is at the center *of the top face*, which is ``(0, 0, 27.4)``. Read that way Mike's sentence is
exactly right and both halves are the same fault: the connector belongs at the top face's center
point and is 15.4 mm below it. If instead he is seeing it off the axis in the GUI, then the
read-back and the screen disagree and that is a third thing to chase.

Either way the two connector findings now pair up: the blade's is on the wrong face and off center,
the fork's is on no face at all. The review currently frames the fork's as a *consistency* problem
between two halves; Mike is framing it as each connector being in the wrong place on its own terms,
which is the stronger and simpler statement.

### New requirement: a bump's edge stands 1 mm clear of the blade's edge

> "The bumps are wrong per a new requirement. Let's require the edge of the bumps to be at least
> 1mm from the edge of the blade."

*(mine)* This is a requirement Mike is adding, not a mistake being found, and the hinge fails it as
built. The blade's toothed face is the Ø``LIMB`` circle cut at ``BLADE/2`` off the limb axis, so its
edge stands ``sqrt(12**2 - 5**2)`` = **10.909** from the pin, the same all the way round and down
the straight sides. A bump's outer edge is ``BUMP_R + BUMP_D/2`` = **10.400**, which leaves
**0.509 mm**. The requirement wants 1.0.

The band's outer radius is what the requirement names, and ``TEETH_R`` is exactly that number, so
the requirement reads ``TEETH_R <= 9.909``. Ways to reach it: bring the band in, make the bump
smaller, or both.

This one and the valley one are the same band seen from its two sides, so they have to be settled
together:

| requirement | what it allows |
| --- | --- |
| bump edge 1 mm inside the blade's edge | ``BUMP_R`` up to 9.109 |
| 1 mm of ear left under a valley | ``BUMP_R`` up to 8.367 |

The fork binds. At ``BUMP_R`` 8.367 the blade margin is 1.741 and the ear under a valley is 1.900,
so both hold with room, and the band becomes about 7.57 .. 9.17 against today's 8.80 .. 10.40. The
price is the lever arm: 87% of today's, so the same bump holds about 13% less angle for the same
force. If the valleys go through instead, the fork's limit disappears and only the blade's 9.109
binds.

*(mine)* Worth Mike knowing: the valley is ``VALLEY_D`` 2.0 where the bump is ``BUMP_D`` 1.6, so the
valley overhangs the bump by 0.2 a side. Every clearance above is figured on the valley where the
fork is concerned and on the bump where the blade is, which is why the two limits differ by more
than the ear's curvature alone explains.

### The round on the ear valley's rim comes out

> "Let's remove the round on the ear valley rim as too small to print."

*(mine)* The feature is ``round ear valley rim``, a Fillet whose radius is ``#rim_break`` = **0.1
mm**. That is under one layer and well under an extrusion width, so no nozzle forms it; the slicer
either drops it or renders it as the sharp edge it was meant to replace. Nothing is lost by deleting
a feature that never reached the plastic.

What the brief claims it was for, and whether that survives: it argued two sharp edges cannot cam,
so the bump's crown was filleted r0.8 — a full hemisphere on a Ø1.6 bump — **and** the valley's rim
broken. With the bump already a dome, only one of the two edges is sharp, and a dome riding a sharp
rim still ramps. The rim break was the smaller half of that pair and the half that cannot be
printed. It also had a hard ceiling of 0.25 mm before neighboring valleys merge into a groove, so
there was never room to make it printable by growing it.

What removing it touches, so nothing is left dangling:

- the hinge tab loses one feature, and ``24 ear valleys`` then patterns the cut alone
- ``#rim_break`` becomes an unused row in ``robot sizes``
- ``instructions/stickbot-draft9p3/source/hinge.rst`` loses the step *Break the dimple's rim* and
  its seven frames, and the pattern step stops saying to click the round as well
- the same step exists in the draft9p0 and draft9p2 pages, which are archival and stay as they are
- ``.docs/experiments/build-briefs/hinge.md`` loses the rim-break argument, the 0.25 ceiling
  arithmetic, and the open question *"how much rim break the valley actually needs"*

If the valleys go all the way through instead, this decides itself: a through hole has a rim on
each face and neither would be broken.

### New requirement: a valley's edge stands 1 mm inside the fork's edge

> "lets require the valley edge to at least 1mm from the fork edge so that there is material to
> build the edge of the fork at 0.4mm nozzle."

*(mine)* The ear's inner face is bounded two ways: by the ``NOSE`` round at r 12 about the pin, and
by the limb's own flanks, which cross that face at **10.613** off the limb axis. The valley ring
reaches r 10.600. So against the round there is 1.400 to spare, and against the flank there is
**0.013 mm**. The two teeth on the flank axis are the ones that fail, which is the same six teeth as
the break-out note above. At a 0.4 mm nozzle 1.0 mm is 2.5 extrusion widths, so the rule buys a
perimeter each side and something between them.

This reads as the in-plane version of the margin Mike asked for earlier, and the two are not the
same number:

| how the 1 mm is measured | allows |
| --- | --- |
| in plane, valley edge to the fork's edge | ``BUMP_R`` up to 8.613 |
| through the wall, valley floor to the outside | ``BUMP_R`` up to 8.367 |

At 8.613 the wall under the valley floor comes out 0.682, so the in-plane rule on its own does not
deliver a millimeter of material; at 8.367 both hold, the in-plane margin being 1.246. **Question
for Mike:** whether the earlier through-thickness margin still stands alongside this one. If it
does, 8.367 is the number and it also satisfies the blade's 9.109; if this in-plane rule replaces
it, the number is 8.613 and the wall under a valley is two-thirds of a millimeter.

Either way the band moves in and the lever arm goes to 87% or 90% of today's.

### Decided: the valleys go all the way through the fork

> "Lets decide to make the valleys go all the way through the fork so that they can be visually
> inspected from the outside and manually cleared out for small printing defects."

*(mine)* This settles the branch Mike opened at the top of these notes, and it retires the
through-thickness margin: there is no wall under a valley to keep, so the 8.367 figure is off the
table and the **in-plane 1 mm from the fork's edge, ``BUMP_R`` <= 8.613, is the rule that stands**.
The two decisions need each other. A through hole at today's 9.60 would not exit as a hole at the
six teeth near the flank; it would tear the flank open into a scallop. Moved in to 8.613, every one
of them is a clean round hole with a millimeter of face around it, which is what makes it
inspectable.

What else follows:

- ``VALLEY_DEEP`` stops being a dimension and joins ``#rim_break`` as a row with nothing left to do
- the bump can no longer bottom in its valley, so the 0.30 mm of clearance the brief works out
  between the crest tip at 6.20 and the valley floor at 6.50 stops being a number anyone has to
  keep. The bump is held by its side against the hole's bore, which is what was carrying it anyway
- the fork gains 48 holes through its flanks, two rows of 24, which is the inspection Mike wants and
  also the first thing anyone will notice about how the robot looks
- each hole breaks out obliquely, because the outer surface is the limb's curve and the hole's axis
  is the pin's; the exit is a slanted oval, not a circle
- the ear is the spring, and these holes are inside its bending span, so ``EAR_I`` and ``EAR_Z``
  computed by ``_seg`` over a solid slice are now optimistic. Given the ear is at 157 MPa on paper,
  losing stiffness here is help, not harm, but the calculation no longer describes the part

**And a collision that has to be settled with it.** Holding Ø2.0 valleys at ``STEP`` 15 deg, the
land between one valley and the next is ``2 r sin 7.5 - 2.0``. At today's 9.60 that is 0.506, thin
already. At 8.613 it is **0.248**, under one 0.4 mm extrusion, so the material between neighboring
holes cannot be printed either. The two rules cannot both hold at 24 teeth of Ø2.0:

| valley | teeth | radius the land needs | radius the edge rule allows |
| --- | --- | --- | --- |
| 2.0 at 15 deg | 24 | >= 9.194 | <= 8.613 |
| 2.0 at 20 deg | 18 | >= 6.911 | <= 8.613 |
| 1.6 at 15 deg | 24 | >= 7.661 | <= 8.813 |
| 1.2 at 15 deg | 24 | >= 6.129 | <= 9.013 |

So either the teeth get coarser or the bumps get smaller. **This one is Mike's**, and it is a feel
decision as much as an arithmetic one: 18 teeth at 20 deg keeps the bump's size and the detent's
strength and gives the joint 20 deg of angular resolution instead of 15; a Ø1.6 valley over a Ø1.2
bump keeps 24 teeth and 15 deg but makes every click smaller.

### If the valleys shrink instead of the teeth thinning out

> "I think per the initial list of problems we can make the valleys smaller. What happens then?"

*(mine)* It works, and it works better than coarsening the pitch, because everything downstream of
the valley is tied to it by a rule already: ``VALLEY_D`` is the bump plus 0.4 of radial clearance,
``BUMP_D`` is the band's width, and the crown fillet is ``BUMP_D/2``, a hemisphere. Shrink the
valley and all four follow. The band also moves back out a little, because the in-plane cap is
``9.613 - VALLEY_D/2``, so a narrower valley buys back some lever arm.

At 24 teeth and 15 deg, with each row at its largest allowed radius:

| valley | bump | ``BUMP_R`` | land | land in 0.4 nozzles | dome r | dome in 0.2 layers | lever |
| --- | --- | --- | --- | --- | --- | --- | --- |
| 2.0 | 1.6 | 8.613 | 0.248 | 0.6 | 0.80 | 4.0 | 90% |
| 1.8 | 1.4 | 8.713 | 0.475 | 1.2 | 0.70 | 3.5 | 91% |
| 1.6 | 1.2 | 8.813 | 0.701 | 1.8 | 0.60 | 3.0 | 92% |
| 1.5 | 1.1 | 8.863 | 0.814 | 2.0 | 0.55 | 2.8 | 92% |
| 1.4 | 1.0 | 8.913 | 0.927 | 2.3 | 0.50 | 2.5 | 93% |
| 1.2 | 0.8 | 9.013 | 1.153 | 2.9 | 0.40 | 2.0 | 94% |

The largest valley that leaves one 0.4 mm land is **1.866**; the largest that leaves two perimeters,
0.8 mm, is **1.512**. So Ø1.5 is the round number that gives the land two passes to build with, and
Ø1.6 is the round number that gives it nearly two.

What does not improve, and is the reason to stop shrinking: the bump has to print as a dome, and its
dome is only ``BUMP_D/2`` tall. At Ø1.6 that is four layers at 0.2, which is a dome. At Ø1.2 it is
three, which is a coarse one. At Ø0.8 it is two, which is a cone with a flat on it, and the whole
argument for filleting the crown — that a dome cams where a square edge scrapes — is gone. **Ø1.2 is
the floor and Ø1.5 or Ø1.6 is the room.**

Three things a smaller valley does **not** fix, so they stay on the list:

- the interference is ``TOOTH_PROUD`` 1.2 against the ear's land at 5.60, which is **0.60 per side**
  whatever the bump's width. The ear gives that on every click, so the click force follows the ear's
  stiffness, not the bump's size. At ``EAR_FREE`` 12 that is around 117 kgf, on the same footing as
  the 195 kgf to press the axle home
- a narrower bump carries the same 0.60 on less contact, so the pressure on it goes up and it is
  likelier to flatten or shear over time
- the dome gets shallower relative to its height, which makes the ramp out of the valley steeper and
  the click sharper and harder rather than crisper

So shrinking the valley settles the printing of the fork's face, and settles it well. It leaves the
snap force exactly where the review left it.

### What narrowing the blade buys, and what it charges for it

> "Let's also look at what a reasonable narrowing of the blade would be to get us a little more
> external margin for a bigger BUMP_R."

*(mine)* It does buy room, and less than one might hope, and it charges for it in the one currency
the joint is already overdrawn in. ``BLADE`` sets ``SLOT`` = blade + 2 ``GAP`` and ``EAR`` =
whatever
the slot leaves of the Ø24. Narrow the blade and the ear's inner face moves outward, so the flank it
has to stay clear of moves outward with it. Rows below hold ``VALLEY_D`` at 1.6 and take the largest
radius the 1 mm rule allows:

| blade | ear | flank | ``BUMP_R`` cap | land | lever | ear I | press force |
| --- | --- | --- | --- | --- | --- | --- | --- |
| 10.0 | 6.40 | 10.613 | 8.813 | 0.701 | 92% | 275 | 195 kgf |
| 9.0 | 6.90 | 10.862 | 9.062 | 0.766 | 94% | 356 | 252 kgf |
| 8.0 | 7.40 | 11.083 | 9.283 | 0.823 | 97% | 451 | 319 kgf |
| 7.0 | 7.90 | 11.278 | 9.478 | 0.874 | 99% | 563 | 399 kgf |
| 6.0 | 8.40 | 11.447 | 9.647 | 0.918 | 100% | 693 | 490 kgf |

Reading it: taking the blade from 10 to 8 is a 2 mm cut that returns **0.47 mm** of band radius, and
the return falls off as it goes, because the flank is a circle and it flattens as it comes round.
Meanwhile the ear thickens by the same 2 mm, and the ear is the spring. Its second moment goes up
64%, and so does everything figured from it: the press force at ``EAR_FREE`` 12 goes from 195 kgf to
319. Narrowing the blade to help the band makes the joint's worst number worse, faster than it makes
the band's number better.

Two things that do not move, which is worth knowing before trading anything for them:

- the detent interference is ``TOOTH_PROUD`` 1.2 against the ear's land, which works out at
  **0.60 per side at every blade width in the table**. The blade's width cancels
- ``MOVE`` is ``STUB_PROUD`` - ``GAP`` = 1.0 at every width too

So the honest answer to "what is a reasonable narrowing": **none of it is reasonable for this
purpose.** ``BLADE`` 9 is the only row that could be called cheap, and it buys 0.25 mm of radius for
a 29% stiffer ear. Shrinking the valley gets the same room for nothing — Ø2.0 to Ø1.6 moved the cap
from 8.613 to 8.813 with the blade untouched, which is 0.2 of the 0.25 that costing 1 mm of blade
would have bought.

If the blade ever does narrow, let it be for its own reasons — the ear being too thin to print
beside a through hole, say — and not to feed the band.

### Blade 9 with a 1 mm slit, and the axle 0.8 proud

> "Let's look at 9mm blade with a 1mm slot in the middle (your old design) to remove stiffness of
> the joint. Let's also make the stub axle 0.8mm proud. How does the stiffness and insertion force
> look then?"

*(mine)* It is the first combination that gets the joint into a range a person could press. Both
halves earn their keep, and they earn it in different ways.

**The slit.** ``BLADE`` 9 with a 1.0 slit leaves two tabs 4.00 across, and an ear 6.90. The ear and
the tab are then springs in series: same force, movement splitting inverse to stiffness. Ear
1235 N/mm, tab 431 N/mm, series **319 N/mm**, against today's solid **955 N/mm**. The slit is worth
**3.0x**, and the softer member does most of the giving: of any move, the tab takes 74% and the ear
26%. Assumed and worth Mike confirming: the tab's free length is 12, the same as the ear's, which is
what a slit running the tongue's full length gives. That number is cubed, so it matters more than
anything else on this page.

**The axle.** ``STUB_PROUD`` 0.8 against ``GAP`` 0.6 leaves ``MOVE`` 0.2, a fifth of today's. Force
is linear in it, so the two changes multiply: **3.0 x 5 = 15x**.

Together, at ``EAR_FREE`` 12:

| | today | proposed |
| --- | --- | --- |
| spring | solid ear, 955 N/mm | ear + tab in series, 319 N/mm |
| ``MOVE`` | 1.00 | 0.20 |
| force to press, both sides | **194.78 kgf** | **13.02 kgf** |
| stress at that force | ear 157.1 MPa | ear 8.7, tab 12.5 MPa |
| against PETG's 50 | 3.1x over | comfortably under |

The stress answer is the one that changes character rather than degree. Today the estimate says the
ear yields on assembly. At 13 kgf nothing in the joint is near yield, so the cantilever arithmetic
stops being a warning and starts being a design.

**The catch, and it is a real one.** ``MOVE`` and the axle's engagement are the same number:
the axle crosses ``GAP`` and whatever is left over is both what the ear has to give and how far the
axle sits in the bore. So this is the whole ladder:

| ``STUB_PROUD`` | engagement | force to press | ear / tab |
| --- | --- | --- | --- |
| 1.6 | 1.00 | 65.1 kgf | 43.7 / 62.5 MPa |
| 1.2 | 0.60 | 39.1 kgf | 26.2 / 37.5 MPa |
| 1.0 | 0.40 | 26.0 kgf | 17.5 / 25.0 MPa |
| 0.8 | 0.20 | 13.0 kgf | 8.7 / 12.5 MPa |

The review already said the axle holds the arm on by one millimeter and called that thin. At 0.8
proud it holds it on by **0.2 mm**, which is half a layer. The slit is free money; the last four
rows of that ladder are all paid for in retention.

**One thing none of these numbers is.** Every force above is the *normal* force to spread the ear,
not the push a child feels. The two differ by the lead-in: the axle is a plain cylinder with a
square edge, so its ramp angle is 90 degrees and no axial push converts into spread at all. Give the
axle's outer edge a 30 degree chamfer and the axial force lands near 1.06x the normal force in
PETG, so 13 kgf normal is about 14 kgf to push. **Chamfering the axle may be worth more than any
number in this section**, because it is what turns the joint from one that cannot be pressed at any
force into one that presses at the force the spring says.

*(mine, and for Mike)* If retention at 0.2 mm is too little, the pair that keeps both ends is
``STUB_PROUD`` 1.2 with the slit and a chamfered axle: 0.60 of engagement, 39 kgf normal, both
members under 40 MPa. And the detent rides the same spring, so its click is
``(TOOTH_PROUD - GAP) x 319`` — at ``TOOTH_PROUD`` 1.2 that is 39 kgf a click, which wants looking
at in its own right.

### Sizing the joint for a 2 kgf press

> "Let's try to get the insertion press force to 2kg. What do you recommend for axle stub height,
> blade width, and blade slit width?"

*(mine)* **Recommended: ``BLADE`` 10 unchanged, slit 7.6, leaving two leaves 1.20 across, and
``STUB_PROUD`` 1.5.** That gives **2.02 kgf** to press, with **0.9 mm of engagement** — within a
tenth of the retention the joint has today, at a ninety-sixth of the force.

| | today | recommended |
| --- | --- | --- |
| ``BLADE`` / slit / leaf | 10 / none / solid | 10 / 7.6 / 1.20 |
| ``STUB_PROUD`` | 1.6 | 1.5 |
| ``MOVE``, which is also the engagement | 1.00 | 0.90 |
| spring | 955 N/mm | 11.0 N/mm |
| press force | 194.78 kgf | **2.02 kgf** |
| worst stress | ear 157.1 MPa | leaf 22.4, ear 1.6 MPa |
| detent, one click | 116.9 kgf | 1.35 kgf |

How the three numbers were picked, in the order they bind:

- **The leaf sets everything.** Once the blade is slit, the leaf is 99% of the spring and the ear
  stops mattering; the whole design problem becomes how thin a leaf may be. At a 0.4 nozzle **1.2 mm
  is three extrusion widths**, which is the floor for something that has to flex without splitting
  along its layers. That fixes the spring at about 11 N/mm.
- **The axle then follows from the target.** 2 kgf against 11 N/mm wants ``MOVE`` 0.89, so
  ``STUB_PROUD`` = 0.89 + ``GAP`` = 1.49, which rounds to **1.5**.
- **The blade width is the one that should not move.** Narrowing it was worth considering only while
  the ear was the spring; with the slit in, blade 9 and blade 10 come out at 11.2 and 11.0 N/mm,
  and blade 9 buys 0.25 mm of band radius for a change that cascades through ``SLOT``, ``EAR``, the
  flank, the valley caps and every drawing on the sheet. **Keep 10.** The slit is then 10 - 2 x 1.2.

Two alternatives, if 1.2 mm of leaf reads too thin to trust:

| leaf | slit | ``STUB_PROUD`` | press | engagement | leaf stress |
| --- | --- | --- | --- | --- | --- |
| 1.2 | 7.6 | 1.5 | 2.02 kgf | 0.90 | 22.4 MPa |
| 1.4 | 7.2 | 1.2 | 2.13 kgf | 0.60 | 17.3 MPa |
| 1.6 | 6.8 | 1.0 | 2.11 kgf | 0.40 | 13.1 MPa |

Every one of them hits 2 kgf; they differ only in how much retention is left. Thicker leaf, less
engagement.

Four things to know before committing:

- **Assumption, and it is the load-bearing one:** the leaf's free length is 12, the same as the
  ear's, which is what a slit running the tongue's whole length gives. It is cubed. If the slit
  stops at the axle instead, the leaf is half as long and eight times stiffer, and none of the
  numbers above survive.
- **Press force and pull-off force are the same force** while the axle is a plain cylinder, so a
  2 kgf joint also comes apart at about 2 kgf. The fix is the usual one for snaps: chamfer the
  axle's outer edge so it leads in, and leave its inner shoulder square so it does not lead out.
  Without that, this whole exercise trades a joint nobody can assemble for one nobody can keep
  together.
- **The tongue keeps its strength.** Two leaves at the outside of the slab hold 55% of the solid
  tongue's bending stiffness, because the material a slit takes out is the material nearest the
  neutral axis. The joint gets soft in the one direction it needs to be soft in.
- **The detent goes soft with it,** to 1.35 kgf a click. Holding torque works out somewhere around
  60 to 120 N-mm against a forearm and gripper that ask for under 10, so it holds, but the margin is
  no longer absurd and ``TOOTH_PROUD`` is now a number worth choosing rather than inheriting.

### Yes, and it changes the answer above

> "When inserting with with blade and fork parallel will the bumps press the leafs out before the
> stub hits?"

*(mine)* Yes, and asking it exposes an error in the section above, which sized the joint off the
axle alone. **The bumps are the insertion load. The axle is a rounding error on it.**

The sequence, with the pins s apart and closing:

- the leading bump enters the slot mouth at **s = 20.8**, because it sits ``BUMP_R`` 8.8 ahead
  of the
  blade's pin and the ear's tip is ``NOSE`` 12 ahead of the fork's
- the axle enters at **s = 12**, by which time **11 of the 24** are already riding the land
- from there every remaining bump joins, and all 24 are on the land for the last 3 mm
- at seating they drop into their valleys together and the whole thing relaxes to nothing

The force through that stroke, for the joint recommended above, counting every engaged contact:

| s | bumps in | from the bumps | from the axle | total |
| --- | --- | --- | --- | --- |
| 20 | 3 | 0.8 kgf | - | 0.8 kgf |
| 12 | 11 | 4.8 kgf | 1.9 kgf | 6.7 kgf |
| 8 | 15 | 11.9 kgf | 1.9 kgf | 13.9 kgf |
| 4 | 21 | 55.7 kgf | 2.0 kgf | 57.6 kgf |
| 2 | 24 | 102.0 kgf | 2.0 kgf | 104.0 kgf |
| ~1.4, where they start to drop in | 24 | ~110 kgf | 2.0 kgf | **~112 kgf** |

**Why it is so much worse than one tooth.** The leaf is rooted at the tongue's root and the ear is
rooted at the rod's end, at opposite ends of the joint, so every contact is soft on one side — but
which side, and how soft, depends on where round the ring the tooth is. A tooth by the blade's tip
runs on a long leaf and gives at 2.1 N/mm. A tooth by the blade's root runs on a leaf 3.2 mm long,
stiff as a wall, and has to lift the ear's tip instead, at 99 N/mm. Summed, the ring is
**962 N/mm — 87 times a single tooth at the leaf's tip**, and it is the teeth near the roots that
carry it. The slit does almost nothing for them.

**``TOOTH_PROUD`` is the lever nobody has chosen.** The interference on the land is
``TOOTH_PROUD - GAP``, exactly parallel to the axle's ``STUB_PROUD - GAP``, and at 1.2 it is 0.60 —
the same interference the axle used to have, times 24 teeth on a stiffer spring.

| ``TOOTH_PROUD`` | land interference | force to lift the ring | detent torque |
| --- | --- | --- | --- |
| 1.20 | 0.60 | 117.6 kgf | 5085 N-mm |
| 0.80 | 0.20 | 39.2 kgf | 1695 N-mm |
| 0.70 | 0.10 | 19.6 kgf | 848 N-mm |
| 0.65 | 0.05 | 9.8 kgf | 424 N-mm |
| 0.60 | 0.00 | none | none |

An arm and gripper ask for well under 10 N-mm to hold a pose. Reaching even 100 N-mm needs an
interference of **0.012 mm**, which no printer resolves. So the band cannot be tuned by its
interference at all: 24 teeth acting together on a ring rooted at both ends is too stiff a system
for the number to have a usable range. **This is structural, not dimensional.**

**One more, from the same geometry.** The dome's radius is ``BUMP_D``/2 = 0.6 and the engagement is
also 0.60, so the bump seats exactly to its equator. At the equator the dome's surface is parallel
to the direction it has to climb, so it does not cam out; it locks. Whatever else changes, the
engagement has to be a fraction of the dome's radius, not all of it.

**What this does to the 2 kgf recommendation.** The three numbers still stand for what they were
solving, the axle's own press. They do not deliver a 2 kgf joint, because the teeth are the load.
The band has to be settled first, and the honest order is: pick what holds a pose, work out what
that costs to insert, then size the axle in what is left.

### Correction: only one tooth carries, and the ~112 kgf was wrong

> "Did you give each tooth the same force or just the 3 or so teeth at the leading edge that press
> the joint apart?"

*(mine)* Each tooth got the same force, independently, and they were summed. That is wrong, and the
number it produced was **eight times too big**.

The leaf and the ear are beams, not a row of separate springs. Pushing the worst tooth out to 0.6
bends the whole leaf, and a cantilever loaded near its root deflects far more further out — at the
governing tooth's station, 3.2 from the leaf's root, the leaf's own tip moves **9.25 times** as far.
So every tooth outboard of the governing one is lifted clear and carries nothing.

Solved properly, as a contact problem with the contact forces free to go to zero:

| s | teeth inside | actually carrying | total | where the load is |
| --- | --- | --- | --- | --- |
| 12 | 6 | 1 | 0.78 kgf | eta +2.3 |
| 8 | 8 | 1 | 1.94 kgf | the axle |
| 4 | 11 | 1 | 9.93 kgf | eta -7.6 |
| 1.4 | 13 | 2 | **14.63 kgf** | eta -8.8, and 0.9 N at the axle |

So the peak is **14.6 kgf, not 112**.

Mike's instinct was right that it is a few teeth, and wrong about which: it is not the leading ones.
The leading teeth touch first, but as deeper teeth enter, they take over and lift the leading ones
off. **The governing tooth is always the last one in** — the one nearest the blade's root, entering
by the ear's tip, where the leaf's lever is 3.2 mm and stiff. It is the same tooth all the way to
seating.

**What this does to the recommendation.** The teeth stop governing as soon as ``TOOTH_PROUD`` comes
down enough for the axle to be the worst contact again:

| ``TOOTH_PROUD`` | peak press |
| --- | --- |
| 1.20 | 15.30 kgf |
| 1.00 | 9.86 kgf |
| 0.90 | 7.13 kgf |
| 0.80 | 4.41 kgf |
| 0.75 | 3.05 kgf |
| **0.70** | **2.02 kgf** |

At 0.70 and below the axle is back in charge and the earlier three numbers stand exactly as they
were. So the recommendation gains a fourth number and loses nothing:

**``BLADE`` 10, slit 7.6, leaves 1.20, ``STUB_PROUD`` 1.5, ``TOOTH_PROUD`` 0.70** — 2.02 kgf to
press, 0.90 mm of engagement, land interference 0.10.

And the detent survives that, because it is the same one-tooth-carries argument in rotation: the
innermost tooth climbing 0.10 takes about 12 N on an 8.8 mm arm, so roughly 200 N-mm over both
faces, against the under 10 N-mm an arm and gripper ask for. The tuning range that looked impossibly
narrow in the section above was an artifact of the same bad model.

*(mine)* Two things still soft in this: the beam model treats the leaf as prismatic when it is a
slice of a circle and its width varies, and it ignores that the two teeth at +/- the same angle sit
at one station and share. Neither moves the conclusion, which is that one contact governs and it is
the trailing one.

#### The same thing said plainly

The joint does not open parallel. It opens as a **wedge**, and the wedge is widest at the blade's
tip. A tooth is touching only where the wedge happens to be exactly as wide as that tooth needs;
everywhere the wedge is wider, the tooth is sitting in air.

Here is the gap at every tooth station at the tightest moment of insertion, 1.4 mm from seated:

| tooth, eta | needs | gap opened | from the leaf | from the ear | |
| --- | --- | --- | --- | --- | --- |
| -8.81, last one in | 0.60 | **0.600** | 0.127 | 0.473 | touching |
| -7.63 | 0.60 | 0.635 | 0.199 | 0.436 | clear |
| -4.41 | 0.60 | 0.739 | 0.404 | 0.334 | clear |
| -2.28 | 0.60 | 0.814 | 0.543 | 0.271 | clear |
| 0.00, the axle | 0.90 | **0.900** | 0.693 | 0.207 | touching |
| +4.41 | 0.60 | 1.086 | 0.985 | 0.101 | clear |
| +8.81, first one in | 0.60 | 1.304 | 1.276 | 0.028 | clear |

Two beams make that wedge, rooted at opposite ends and each widening toward its own free end. The
leaf is rooted at the blade's root, so its share grows toward the blade's tip: 0.127 at the deepest
tooth, 1.276 at the leading one. The ear is rooted at the other end and does the opposite: 0.473
down to 0.028. Their sum still widens toward the blade's tip, from 0.600 to 1.304.

So the leading tooth needs 0.60 and is sitting in 1.30 — seven tenths of a millimeter of air. It
touched earlier in the stroke, when it was the deepest thing in the slot and the wedge pivoted about
it. It stopped touching the moment something deeper came in and took the pivot over.

That is the handover, and one word in it matters: the tooth that carries is the **newest one in**,
which is the one nearest the slot's mouth, not the one deepest inside. It carries because it is the
tooth closest to the leaf's own root, where the leaf is short and stiff and can hardly bend.
Levering
the joint open there swings the leaf's far end wide, and everything deeper is left hanging. The load
never spreads across the teeth; it hands off from one to the next as each new one enters.

Two contacts appear in the table rather than one only because the axle asks for 0.90 where its
neighbors ask for 0.60, so it pokes through a wedge that has already opened to 0.900 there. It is
carrying 0.9 N against the tooth's 70.9.

#### The pictures

Open `.docs/reviews/hinge/changes-pictures.html`. Three drawings, generated by
`.docs/reviews/hinge/wedge_figures.py` from the same numbers as the table above, so a drawing
cannot disagree with it.

- **Each half bends about its own root.** The leaf rooted at the mouth, the ear rooted at the far
  end, each drawn as it actually bends. Left to right is true scale; up and down is four times
  bigger, or the bend would be invisible.
- **The joint opens as a wedge.** The two halves put together, with the air between them shaded.
  Each tooth is drawn at the height that tooth needs. The tooth at the mouth reaches the ear; the
  rest fall short, by 0.704 mm at the far end.
- **Through the stroke the load hands off.** The same joint at four points on the way in. Every
  tooth that is touching carries a number; there is only ever one worth reading, and it is always
  the tooth nearest the mouth, which is the one that just went in.

### Root the leaf and the ear farther out

> I think they mean we like root for the leaf and ear to be farther from center of the joint so
> they are springier without weakening the structure?

Yes, and it is a bigger lever than it looks. It is also the only lever found so far that lowers the
press force and the stress at the same time, and it costs no material.

*(mine)* Two things follow that were not obvious before the pictures.

**The length that governs is not 12. It is 3.2.** The teeth are a ring of radius `BUMP_R` = 8.813,
so the deepest tooth station sits 8.813 nearer the root than the pin does. With the ear rooted at
12 that tooth cantilevers on 12 − 8.813 = 3.19 mm, not 12. Rooting at 21 takes the same arm to
12.19, which is 3.8 times longer, so 55 times softer. The same is true of the leaf against the
blade's root. All the old arithmetic put the load at the pin and therefore flattered the joint.

**The numbers `make_plans.py` already types are the ones this asks for.** `BLADE_OUT` = 32 puts the
blade's root 20 mm from the pin; `SLOT_DEEP` = 33 measured from the fork's tip puts the fork's root
21 mm from the pin. What buries them is the limb, which unions a rod that stops at `NOSE` = 12 and
fills the rest of the slot back in. The rounding rule only says the rod must stop **at least**
`NOSE` from the pin so it clears the other member's swing; it does not say the rod must stop there.
Pulling each rod back to its own root is geometrically free: nothing on either member reaches past
radius 12 from the pin, and both roots are outside that.

So the correction is not to derive `BLADE_OUT` down to `2 * NOSE`. It is to leave 32 and 33 alone
and stop the limb from filling them in. That reverses the settled item in the review's last
section, and it reverses the `EAR_FREE` edit sitting uncommitted in `make_plans.py`.

#### What it buys

Peak press force through the stroke, from the same contact solve as the pictures. Roots are given
as blade / fork, in millimeters from the pin.

| blade | roots | tooth | press | ear root |
|---|---|---|---|---|
| solid | 12 / 12 (what prints today) | 1.2 | 2092 kgf | 644 MPa |
| solid | 20 / 21 | 1.2 | 80.5 kgf | 73.4 MPa |
| slit 7.6 | 12 / 12 | 1.2 | 14.63 kgf | 21.7 MPa |
| slit 7.6 | 12 / 12 | 0.70 | 2.01 kgf | 1.8 MPa |
| slit 7.6 | 20 / 21 | 1.2 | **1.34 kgf** | **2.8 MPa** |

The last two rows are the point. The earlier recommendation reached 2 kgf by shaving the tooth from
1.2 to 0.70, and a tooth is what holds the angle, so it paid for the press with the hold. Moving
the roots reaches 1.34 kgf with the tooth left at its full 1.2. Same press by hand, twice the
detent.

The two roots are not equally worth moving, because the leaf is the softer member:

| | fork 12 | fork 16 | fork 21 |
|---|---|---|---|
| **blade 12** | 14.63 | 9.64 | 6.11 |
| **blade 16** | 4.72 | 4.05 | 3.25 |
| **blade 20** | 1.54 | 1.46 | 1.34 |

Moving the blade's root alone takes 14.63 to 1.54. Moving the fork's root alone takes it to 6.11.

#### What it does not buy

It does not rescue a solid tongue. At 20 / 21 a solid tongue still wants 80 kgf, because with no
slit the ear is the only spring in the joint. The slit is doing work no root position can do, and
the two changes multiply rather than substitute. Any decision to move the roots is still also a
decision about the slit.

#### What it costs

The section over the newly exposed stretch, against the round rod it replaces:

| | mm⁴ | of the rod | stress |
|---|---|---|---|
| round rod | 16286 | 100 % | ×1.00 |
| the two ears, swinging | 4741 | 29 % | ×3.43 |
| the two ears, spreading apart | 550 | 3.4 % | ×29.6 |
| solid tongue, swinging | 10547 | 65 % | ×1.55 |
| the slit tongue's two leaves, swinging | 2224 | 14 % | ×7.32 |

So it does weaken the limb, and here is the honest size of it. In the swing plane, which is where a
limb is loaded, the fork's slotted stretch carries about three and a half times the stress the rod
would. That stretch already exists; the change makes it 21 mm instead of 12. Sideways, the ears
alone are thirty times worse, but the tongue is inside the slot with `GAP` each side, so the joint
rattles 0.6 mm and then bears rather than folding.

The bending moment at the ear's root under a service load barely changes, because moving the root
9 mm along a limb whose load is 150 mm away is nothing. What changes is which section carries that
moment.

The rod loses the length the joint gains. On a 48 mm segment with a 9 mm socket at the far end, the
rod goes from 27 mm to 18 mm, so a little under half the segment becomes fork. Two of these meet at
every elbow and knee, which is worth looking at on screen before it is worth arguing about.

**Mike decides:** whether the limb's rods pull back to 20 and 21, which is what the plan sheet
already draws.

### How strong the joint is, as a torque

> Please summarize in a way that I can quantify how strong the joints are in terms of breaking
> torque (foot pounds) in the various strong and weak axis for the blade and the fork.

*(mine)* Four points, then the two tables.

**Strength is a section property, so moving the roots does not change any of it.** Where a beam is
rooted sets how hard it is to bend, not how much it takes to break it. Every number in the breaking
table below is the same at roots 12 / 12 and at roots 20 / 21. What the roots change is the press
force and the holding torque, which are the second table.

**Nothing in this joint ever reaches its breaking torque.** The teeth let go first, by a factor
between thirty and seven hundred. So the honest answer to "how strong is the joint" is the torque
at which it slips, not the torque at which it snaps.

**The number to hold everything against is 26 N.mm.** One arm below an elbow is about 55 g of PETG
with its weight 48 mm out, so an elbow needs 26 N.mm, which is 0.019 ft.lb, just to stop the arm
drooping. Every useful torque in this joint is a small multiple of that.

**That number kills the 2 kgf recommendation.** Shaving the tooth to 0.70 leaves 0.10 mm of
interference and a slip torque of 7.5 N.mm. The arm falls under its own weight. The recommendation
was sized on the press force alone and never checked against the hold.

#### Breaking torque

Bulk PETG at 50 MPa, and 29 MPa in shear. Swing is bending in the plane the joint hinges in;
sideways is bending out of it, which is the direction that pries the ears apart; twist is about the
limb's own axis. The last two columns are the push at the next joint out, 48 mm away, that would
reach the break.

| section | swing | sideways | twist | swing | sideways |
|---|---|---|---|---|---|
| round rod, Ø24, the limb itself | 50.0 ft.lb | 50.0 ft.lb | 57.8 ft.lb | 144 kgf | 144 kgf |
| the fork: its two ears | 16.5 | 5.4 | 6.3 | 47 kgf | 15.5 kgf |
| the blade: a solid tongue, 10 wide | 35.7 | 14.0 | 5.8 | 103 kgf | 40 kgf |
| the blade: a tongue slit 7.6 | 7.5 | 0.4 | 0.4 | 22 kgf | 1.1 kgf |

The axle is not the weak link: shearing the Ø4.0 stub off takes 74 kgf, and crushing the 1.0 mm
that is engaged takes 41 kgf.

The slit tongue's 0.4 ft.lb sideways and in twist is the worst number in the robot, but it is
pessimistic, because a tongue on its own is not how the joint is loaded. The tongue sits in the
slot with `GAP` each side, so it bears on the ears after 0.6 mm and they carry it. Read the
assembled joint's weak axis as the fork's 5.4 ft.lb.

So the joint's weak axis is about a third of its strong axis, and its strong axis is about a third
of the limb it is set into. Nothing here is fragile.

#### Holding torque, which is what actually gives

The torque that walks the teeth one notch, from the same contact solve. `delta` is
`TOOTH_PROUD - GAP`, the height the joint has to open to let a tooth climb out.

| | press | hold | as a mass at the next joint |
|---|---|---|---|
| roots 12 / 12, tooth 1.2 (what prints today) | 14.63 kgf | 329 N.mm, 0.243 ft.lb | 699 g |
| roots 12 / 12, tooth 0.70 (the 2 kgf study) | 2.01 kgf | 7.5 N.mm, 0.006 ft.lb | 16 g |
| roots 20 / 21, tooth 1.2 | 1.34 kgf | 30 N.mm, 0.022 ft.lb | 64 g |
| roots 20 / 21, tooth 1.8 | 2.69 kgf | 121 N.mm, 0.089 ft.lb | 257 g |
| roots 20 / 21, tooth 2.4 | 4.03 kgf | 272 N.mm, 0.200 ft.lb | 577 g |

Read down the column: today's joint holds well and cannot be assembled. The 2 kgf study can be
assembled and cannot hold. Moving the roots and raising the tooth together gets both, because the
press force falls with the cube of the root length while the hold falls only with `delta`, so the
tooth can be bought back much more cheaply than it was sold.

Row four is the one to look at: **roots 20 / 21 with the tooth at 1.8**. It presses together at
2.69 kgf, which a middle-schooler can do, and it holds 4.7 times the arm's own weight, which is
about a third of what prints today.

A taller tooth is not free. It needs a valley that seats it, so `TOOTH_PROUD - VALLEY_DEEP` has to
stay inside `GAP`, and a taller dome on the same `BUMP_D` is a sharper cone. Both of those run into
the two 1 mm edge rules already settled above. That is the next thing to size, not another press
force.

**Mike decides:** whether the target is a press near 2.7 kgf with a 1.8 tooth, or some other point
on that table.

### Sized: the roots, then the valley

> Let's go with roots that are close to 4 kgf with tooth 1.8, size the roots, and then size the
> valley

*(mine)* Sizing the roots turned up a constraint that was not written down anywhere, and it moves
the axle, so it comes first.

#### The axle has to outlast the tooth

All the teeth ride onto their lands at the same moment, because they are one ring at one phase, so
turning the joint one notch lifts the whole ear by `TOOTH_PROUD - GAP`. The axle sits in the middle
of that ring and is lifted with it. If the axle is engaged by less than the tooth climbs, the arm
comes off instead of clicking.

So `STUB_PROUD` is not a free number. It is

    STUB_PROUD >= TOOTH_PROUD + margin

Today's joint passes by luck: a 1.2 tooth climbs 0.6 and a 1.6 axle is engaged 1.0, so there is
0.4 in hand. Keeping that same 0.4 of margin, **a 1.8 tooth needs a 2.2 axle**. Every earlier
sizing on this page held the axle at 1.5 or 1.6 and is wrong for a tooth taller than that.

#### The roots

With the tooth at 1.8, the axle at 2.2, a 10 mm tongue slit 7.6, and the two roots one millimeter
apart the way `SLOT_DEEP = BLADE_OUT + 1` already has them, a 4.00 kgf press wants the blade rooted
**18.2 mm** from the pin and the fork **19.2 mm**. The tooth count barely moves it, because the
axle and the two end stations set the answer.

Round them to 18 and 19 and the press lands between 4.06 and 4.47 kgf, depending on the count.

The two lengths that carry this should be named for what they are, which also settles the review's
complaint that `BLADE_OUT` is typed where a rule exists. The spring length is the design variable;
the slot depth follows from it:

    TAB_FREE  = 18                          # the leaf, blade root to the pin
    EAR_FREE  = 19                          # the ear, fork root to the pin
    BLADE_OUT = TAB_FREE + NOSE             # 30
    SLOT_DEEP = EAR_FREE + NOSE             # 31

Both are past `NOSE`, which is all the rounding rule asks. The rod on each limb loses what the
joint gains: 27 mm becomes 20 on the fork's limb and 26 becomes 20 on the blade's. That is the one
thing on this page worth looking at on screen before agreeing to it.

#### The valley

Two rules bind it, and only one of them ever wins. The fork's edge is at r 10.613 and the blade's
at r 10.909, so a valley may reach r 9.613 and a bump r 9.909. Since the valley is the bigger
circle, the valley rule always binds and the bump gets the slack. That gives

    BUMP_R = 9.613 - VALLEY_D / 2

The third rule is the land between one valley and the next, which is now a wall right through the
ear rather than a floor, because the valleys go all the way through. A wall wants two 0.4 beads, so
the land wants 0.8. Taking the largest valley that leaves 0.8:

| | valley | bump | BUMP_R | land | bump to the blade's edge | step |
|---|---|---|---|---|---|---|
| 24 teeth | 1.5 | 1.1 | 8.863 | 0.814 | 1.496 | 15° |
| **20 teeth** | **1.8** | **1.4** | **8.713** | **0.926** | **1.496** | **18°** |
| 16 teeth | 2.4 | 2.0 | 8.413 | 0.883 | 1.496 | 22.5° |
| 16 teeth, roomier | 2.0 | 1.6 | 8.613 | 1.361 | 1.496 | 22.5° |

24 teeth falls away: a Ø1.1 bump standing 1.8 proud is a spike, not a dome. The choice is really
20 or 16.

At roots 18 and 19, with the tooth at 1.8 and the axle at 2.2:

| | press | ear stress | hold | against the arm's own weight |
|---|---|---|---|---|
| 24 teeth | 4.47 kgf | 8.8 MPa | 201 N.mm | 7.7× |
| **20 teeth** | **4.33 kgf** | **8.5 MPa** | **162 N.mm** | **6.2×** |
| 16 teeth | 4.06 kgf | 7.9 MPa | 122 N.mm | 4.7× |
| 16 teeth, roomier | 4.24 kgf | 8.3 MPa | 127 N.mm | 4.9× |

**Recommended: 20 teeth at 18°, a Ø1.8 valley, a Ø1.4 bump on r 8.713.** It presses at 4.33 kgf,
holds 6.2 times the arm's own weight, works the ear to 8.5 MPa against PETG's 50, and leaves 0.926
of land, which is two beads and a bit.

The one thing 20 teeth gives up is 45°. A 24-tooth ring hits it and a 16-tooth ring hits it; an
18° ring goes 36°, 54°. If a robot posed at 45° matters more than the finer step, take the last row
instead: 16 teeth, a Ø2.0 valley, a Ø1.6 bump on r 8.613, and 1.361 of land, which is the most
comfortable set of numbers on the page.

#### What falls out of the design

- `VALLEY_DEEP` goes. The valley is a through hole, so there is no floor and no 0.30 clearance to
  quote. The tooth enters 1.20 mm into a wall that is 2.65 mm thick at its thinnest, so it never
  shows through the outside.
- The rim round is already gone by the decision above.
- The bump stops being a hemisphere. At 1.8 proud on Ø1.4 it is a 1.1 mm post capped with an r0.7
  dome. The brief's rule still reads the same way, fillet the crown at the bump's own radius, but
  the shape it produces is a domed post, not a ball.
- Nobody has printed this joint, and a 1.8 mm post hanging off a downward-facing tongue is a longer
  unsupported feature than a 1.2 mm one. That is a print-orientation question, not an arithmetic
  one.

#### The whole set

    GAP        0.6      unchanged
    BLADE      10       unchanged
    SLIT       7.6      two 1.2 leaves
    TAB_FREE   18       new; BLADE_OUT = TAB_FREE + NOSE = 30
    EAR_FREE   19       new; SLOT_DEEP = EAR_FREE + NOSE = 31
    TOOTH_PROUD 1.8
    STUB_PROUD  2.2     = TOOTH_PROUD + 0.4
    STEP       18       20 teeth
    VALLEY_D   1.8      through the ear
    BUMP_D     1.4
    BUMP_R     8.713    = 9.613 - VALLEY_D / 2

### Correction: the 0.4 is dead play, not clearance

> We're saying the valley is required to be 0.4 more diameter than the bump and the land is the
> space between valleys?

*(mine)* The land, yes. The 0.4, not really, and asking about it found a fault in the 20-tooth
recommendation above.

**The land** is the wall between one valley and the next, measured along the chord joining their
centers: `2 * BUMP_R * sin(180 / n) - VALLEY_D`. Since the valleys now go all the way through, that
wall is a wall in the full sense, standing the ear's whole thickness, which is why it wants two
beads rather than one. There is a second gap, the flat between one bump and the next on the blade,
which is `chord - BUMP_D`. It is always the easier of the two and it never governs.

**The 0.4** was carried over from today's Ø2.0 valley and Ø1.6 bump. It is not derived. What it has
to do is let the bump sink into the valley without its side jamming on the wall, so the requirement
is `VALLEY_D >= BUMP_D` plus enough for a printed hole and a printed post to fit. 0.2 a side is a
fair number for that.

**But it is not free, and at a 1.8 tooth it stops being clearance and becomes play.** A seated bump
sinks `TOOTH_PROUD - GAP` below the ear's face. The bump's widest point is `BUMP_D / 2` down from
its tip, where the dome meets the shank. So:

- if `TOOTH_PROUD - GAP <= BUMP_D / 2` the ear's face meets the bump on its **dome**, which is
  curved, so any sideways movement starts climbing at once and the spring pushes it back
- if `TOOTH_PROUD - GAP > BUMP_D / 2` the ear's face meets the bump on its **straight shank**, and
  a straight shank in a straight hole has no restoring force at all

Today's joint is the first case: a 1.2 tooth sinks 0.6 against a 0.8 dome, so there is no play. The
20-tooth recommendation above is the second case: a 1.8 tooth sinks 1.2 against a 0.7 dome, so the
0.4 becomes **0.2 a side of dead rotation, which is 1.3° at every notch**, about 2 mm at the end of
an arm. I did not catch that when I sized it.

#### The rule that was missing

    BUMP_D >= 2 * (TOOTH_PROUD - GAP)

A tall tooth needs a fat bump, and a fat bump needs a fatter valley, and a fatter valley needs more
pitch, so it costs teeth. That makes this a three-way trade where two of the three can be had:

| | teeth | step | bump | valley | BUMP_R | land | press | hold |
|---|---|---|---|---|---|---|---|---|
| tall tooth, fine step, **1.3° of play** | 20 | 18° | 1.4 | 1.8 | 8.713 | 0.926 | 4.33 kgf | 162 N.mm, 6.2× |
| tall tooth, no play, **coarse step** | 12 | 30° | 2.4 | 2.8 | 8.213 | 1.451 | 3.89 kgf | 88 N.mm, 3.4× |
| tall tooth, no play, middle step | 16 | 22.5° | 2.4 | 2.8 | 8.213 | 0.405 | 3.89 kgf | 117 N.mm, 4.5× |
| fine step, no play, **short tooth** | 24 | 15° | 1.6 | 2.0 | 8.613 | 0.248 | 2.12 kgf | 48 N.mm, 1.8× |

The last row is today's tooth on the new roots. It has no play and the finest step, and it holds
1.8 times the arm's own weight on a 0.248 land, which is under one bead.

**Revised recommendation: 12 teeth at 30°, a Ø2.4 bump, a Ø2.8 valley on r 8.213.** No dead play,
1.451 of land and 1.851 of flat, which are the roomiest numbers anywhere on this page, 3.89 kgf to
press, and 3.4 times the arm's weight held. The step lands on 0°, 30°, 60° and 90°, so it keeps
what the multiple-of-four rule was protecting and gives up 45°.

The 16-tooth row keeps 45° and a finer step for the same bump and valley, but its land is 0.405,
which is exactly one bead and no margin. It is the row to take if 22.5° matters; it is not the row
to take if the land is what worries you.

**Mike decides:** how much dead play a notch may have, which is what picks between rows one and
two.

### Correction: the section above is wrong twice over

> How are you getting rid of play without making the bottom of the bump wider than the valley?

*(mine)* I am not. There is no way to, and the rule I wrote to buy it is backwards.

**Play cannot be removed.** The tooth passes through the ear's face at height `GAP` above the
blade's face. Its radius there is some `R(GAP)`. The valley's radius is `VALLEY_D / 2`. The play is
the difference:

    play = VALLEY_D / 2 - R(GAP)

For the tooth to sink into the valley at all, the valley has to be wider than the tooth is at that
plane, by at least enough for a printed hole and a printed post to go together. So the play is
never less than the printing clearance, whatever the diameters are. Measured:

| | play | at its radius |
|---|---|---|
| today, tooth 1.2 on a Ø1.6 bump | 0.225 mm | 1.35° |
| the 20-tooth row, tooth 1.8 on a Ø1.4 bump | 0.200 mm | 1.32° |
| the 12-tooth row, tooth 1.8 on a Ø2.4 bump | 0.200 mm | 1.40° |

They are all the same number. The column headed "no play" was fiction, and so was the claim in the
paragraph above it that today's joint has none.

**What I was actually looking at is whether the tooth can climb out at all**, which is a different
property, and I stated its rule the wrong way round. A domed post's widest point, its equator, sits
at `TOOTH_PROUD - BUMP_D / 2` above the blade's face. The ear's face sits at `GAP`. What matters is
which is higher:

- equator **below** the face: the face meets the tooth on the narrowing dome, which is a slope, so
  the tooth rides up it and out
- equator **at** the face: the tooth's surface there is vertical, so the ramp is infinite
- equator **above** the face: the face meets the straight shank, and the tooth is undercut

Written out, riding out needs `BUMP_D > 2 * (TOOTH_PROUD - GAP)`, which is the inequality I wrote,
but I then chose numbers that make it an equality and called them the safe ones. Ø2.4 with a 1.8
tooth puts the equator at exactly 0.60, which is exactly the face. That row is a locked joint.

**And the row I recommended before it is worse.** 20 teeth, a Ø1.4 bump, a 1.8 tooth: the equator
is at 1.10 and the face at 0.60, so the face cuts the straight shank half a millimeter below the
widest point. That tooth is undercut. Once seated it does not click, it holds until something
breaks.

So of the four rows in that table, two are joints that cannot be turned, and the property the table
was sorted on does not exist.

**How I got it wrong.** I reasoned that a straight shank in a straight hole gives no restoring
force, which is true, and concluded that the bump should be made fatter until the shank was out of
the way. Making it fatter moves the equator *down*, toward the blade's face and away from the ear's
face. I never worked out which side of the face the equator landed on; I asserted the rule from the
shape of the argument instead of computing the contact. The arithmetic that would have caught it is
one line and is now written above.

Nothing in the sizing before this section is affected except through `BUMP_D` and `TOOTH_PROUD`:
the roots, the two 1 mm rules, the land definition, and the axle rule all still stand.

### The fork's face at 5.20, and a cone with a flat top

> Let's move the forks inner face to +/-5.20mm. Let's make the bumps be cones with a flat top.
> Let's design the valleys to be 1.2mm diameter. What is the bump size at a 45 degree slant with a
> 0.2mm flat top that nominally contacts the 1.2mm diameter valley. I think it is 2*(0.6+0.2)
> 1.6mm diameter base of the bump. I think we can fit 24 teeth.

*(mine)* The base is 1.6, 24 teeth fit with room to spare, and the cone does the one thing the
dome could not.

**The base.** The cone has to be Ø1.2 where it crosses the ear's face, which is `GAP` = 0.20 above
the blade's face, and at 45° the radius grows one for one with the rise. So the base radius is
0.60 + 0.20 and the base is **Ø1.60**, which is the arithmetic in the question.

**The height is a separate number, and the flat top sets it.** The base and the slant fix where the
cone seats; the flat top fixes how tall it is, and therefore how far the joint has to open to let it
out. Running from Ø1.60 at the base to the flat at 45°:

| flat top | height | climb, `TOOTH_PROUD - GAP` | axle, at `TOOTH_PROUD + 0.4` |
|---|---|---|---|
| 0.2 | 0.70 | 0.50 | 1.10 proud, 0.90 engaged |
| 0.4 | 0.60 | 0.40 | 1.00 proud, 0.80 engaged |

A 0.2 flat is half a nozzle, so it will come out as a rounded point rather than a flat. Size it at
0.4 and take the 0.60 tall cone; a rounded tip is better for camming anyway.

**The cone removes the play, and it does it by seating on a taper.** A cone landing on the valley's
rim centers itself: any difference between the printed hole and the printed cone is taken up by the
cone sitting a little deeper or a little shallower, not by sliding sideways. That is the thing a
domed post in a straight hole cannot do at any diameter.

**24 teeth.** With the fork's face at 5.20 the ear's edge moves out to r 10.8148, so a valley may
reach r 9.8148 and a bump r 9.9087. The bump is now the bigger circle, so for the first time the
**bump rule binds**: `BUMP_R = 9.9087 - 0.80 = 9.109`.

| teeth | step | land between valleys | flat between bumps | hits 45° |
|---|---|---|---|---|
| 32 | 11.25° | 0.586 | 0.186 | yes |
| 28 | 12.86° | 0.840 | 0.440 | no |
| **24** | **15°** | **1.178** | **0.778** | **yes** |
| 20 | 18° | 1.650 | 1.250 | no |

24 is comfortable: nearly three beads of land and nearly two of flat. 28 would build but misses 45°.
32 leaves 0.186 between bumps, which is under half a bead.

**What moving the face to 5.20 costs and pays.** The slot narrows to 10.4, so the ear thickens from
6.4 to 6.8 and its second moment rises from 275.2 to 338.3, a 23 % stiffer spring. Against that,
the climb falls from 0.60 to 0.40, and force goes as the climb. The climb wins.

#### The numbers, and a measure I had wrong

Press through the stroke and breakaway torque, 24 teeth on r 9.109, a 10 mm tongue slit 7.6.

| roots | flat | climb | press | breakaway | against the arm's weight | ear |
|---|---|---|---|---|---|---|
| 14 / 15 | 0.4 | 0.40 | 5.64 kgf | 504 N.mm | 19.4× | 8.3 MPa |
| **16 / 17** | **0.4** | **0.40** | **2.99 kgf** | **268 N.mm** | **10.3×** | **4.8 MPa** |
| 17 / 18 | 0.4 | 0.40 | 2.21 kgf | 197 N.mm | 7.6× | 3.7 MPa |
| 18 / 19 | 0.4 | 0.40 | 1.66 kgf | 148 N.mm | 5.7× | 2.8 MPa |
| 18 / 19 | 0.2 | 0.50 | 2.07 kgf | 185 N.mm | 7.1× | 3.6 MPa |
| 20 / 21 | 0.4 | 0.40 | 0.95 kgf | 85 N.mm | 3.3× | 1.7 MPa |

**The torque column is not the same measure as the one in the tables above it.** Those quoted the
work to cross a whole notch divided by the notch's angle, which is an average over a stroke that is
mostly flat sliding. What holds a joint is the peak, at the top of the ramp, and for a 45° cone
that is exactly `press force x BUMP_R` because the tangential and axial components are equal. The
earlier averages understate the hold and should not be compared against this column.

A solid tongue is still hopeless: 70 kgf even at roots 20 / 21. The slit is not optional.

**Roots 16 and 17 look like the pick**: `BLADE_OUT` 28, `SLOT_DEEP` 29, a 3 kgf press, ten times the
arm's own weight held, and the ear worked to 4.8 MPa against PETG's 50. The rods lose less than
they would have at 18 and 19.

#### Two things to watch

- `GAP` = 0.2 is now doing two jobs: it sets where the cone seats, and it is the clearance for a
  10 mm tongue in a 10.4 slot. On an X1C a slot prints narrow and a tongue prints wide, so 0.2 a
  side could close up to nothing and the tongue would bind before the teeth ever met. If that
  happens the way out is to relieve the slot to 11.2 everywhere except the toothed band, so the
  seat keeps 0.2 and the fit gets 0.6.
- The cone lands on a sharp hole rim, which is a line contact. That is a real cam, but the rim will
  wear or crush a little on the first few cycles, which will lower the hold from the numbers above.

**Mike decides:** the roots, and whether the slot is relieved outside the band.

### Drawn: the relieved slot, and the rim that does not stay sharp

Open `.docs/reviews/hinge/seat-pictures.html`. Two drawings, generated by
`.docs/reviews/hinge/seat_figures.py` from the same numbers as the section above.

**`seat.svg` — where a 0.20 seat and a 0.60 fit can both live.** Sectioned across the pin, drawn
260 times full size, so left to right is distance out from the pin and up the page is along it. Two
ways to get both numbers at once, and they are not quite equal:

- Relieve the slot to 11.2 and leave a raised band, 2.4 wide, on the inside of each ear. The cone
  goes on the tongue at 5.0, where the limb's round is still far away, so the bump may sit at
  r 9.109.
- Or leave the slot flat at 11.2 and raise the band on the tongue instead. That puts the cone's
  base at 5.4, where the round has already begun to close in, so the bump has to come in to
  r 8.915 and the joint gives up a little of its lever.

Either way the tongue keeps 0.60 a side over nearly all of its area and the cone still crosses the
ear's face 0.20 up, which is what fixes the Ø1.2 valley and the Ø1.6 base. The band is the only
place either part is held to a print tolerance.

**`rim.svg` — the cone lands on a corner, and the corner does not stay sharp.** The same cone and
valley at 150 times full size, in three states: seated new with the faces 0.200 apart and 0.400 of
climb left; at the top of the climb with the faces 0.600 apart, riding the land; and seated again
after the rim has worn 0.10, with the faces 0.341 apart and 0.259 of climb left.

A round on the rim, designed in or worn in, holds the cone up off its seat by 1.414 times the
radius, so the joint loses that much climb before it starts to turn:

| rim round | climb | holds |
| --- | --- | --- |
| 0.00 | 0.400 | 100% of new |
| 0.05 | 0.329 | 82% |
| 0.10 | 0.259 | 65% |
| 0.15 | 0.188 | 47% |

Two consequences. The 0.1 round that used to sit on the valley's rim was worth taking off, and it
must stay off. And the joint will feel looser after a few dozen presses than it does on the first
one, so the tooth is sized for the worn number, not the new one; the 3 kgf press at roots 16 and 17
is the new number, and two thirds of its hold is what to plan on.

### Settled: one raised land, chamfered coming and going

> make the band that is 0.20 at the seat, 1 rectangle that is as wide as the leaf and is
> chamfered rising up to it in both coming and going, but only covers the length a little past
> widest valley

Drawn in `seat.svg`, which now has three panels: the ear's inner face looked at along the pin,
a section down the slot on the middle line, and the true-scale section out across the width.
`seat_figures.py` generates all three.

The slot is relieved to 11.2 everywhere. One land, and only one, stays at 10.4:

| | |
| --- | --- |
| along the slot | 20.8, that is 10.4 each way from the pin |
| across the width | 21.2, which is the whole face; the rod's round ends it at 10.61 |
| how proud | 0.40 a side, which is what leaves the 0.20 fit at the seat |
| the two ends | chamfered 0.4 in 1.2, an 18° ramp |
| clear of the valleys | 0.69 past the widest part of the ring, which reaches 9.709 |

Why it is a rectangle and not a ring. A ring at the tooth radius would have an inner step and an
outer step as well as the two ends, and the tongue's face would have to cross all four. A rectangle
as wide as the leaf runs off both sides of the face, so there is no side step at all; only the two
ends are steps, and both of them are chamfered. Nothing on either part ever meets a square edge.

Why it stops at 10.4. The tongue enters over the ear's tip at 12. If the land ran to the tip the
tongue would meet a 0.4 step in the mouth of the slot. Stopping at 10.4 and ramping out to 11.6
leaves 0.4 of relieved face at the mouth, so the tongue is already guided before it starts to
climb. The far end is the same in reverse: the tongue's nose reaches 12 past the pin when it
seats, so it runs off the far end of the land and needs the ramp there too, coming and going.

Two things the drawing shows that the arithmetic did not:

- The face is 21.2 across, not 24. The ear is what is left of a Ø24 rod after an 11.2 slot is cut
  through it, so its inner face runs out where the rod's own round reaches that depth, at 10.61.
  The land, being 0.2 closer to the mid-plane, gets to 10.81. Either way the valley ring's outer
  edge at 9.709 has under a millimeter of face outside it.
- The leaf's face is 21.8 across by the same arithmetic at 5.0, so the leaf is a touch wider than
  the land. That is the right way round: the land is fully covered in every position.

The axle is drawn in the second panel. It stands 1.00 proud into a bore whose mouth is now the land
at 5.20, so 0.80 is engaged against a 0.40 climb, which still satisfies the rule that the axle must
out-engage the tooth.

### Decided: roots 16 and 17, a 0.4 flat top, and the slit rederived

> Let's go with roots 16 and 17 and a 0.4 flat top. Rederive the slit. Move the fork's robot
> connector. The part names become forks and blade.

Taken as: the parts are named `fork` and `blade`, one name each.

#### The slit is not optional, and 7.6 was too much

A solid tongue at roots 16 and 17 needs **206 kgf** to press together. The ear on its own cannot be
the spring; the joint has to open as a pair of springs in series, and the second one is the tongue.

The slit's width is the only thing left free, and it is a straight trade. A wider slit gives thinner
leaves, which press easier and hold less, and which snap sideways sooner. Everything below is at
roots 16 and 17, 24 teeth, a 1.6 cone with a 0.4 flat top, a 0.40 climb and the axle 1.00 proud:

| slit | each leaf | press, kgf | hold, N·mm | after 0.10 of wear | sideways, at the hand |
| --- | --- | --- | --- | --- | --- |
| 4.0 | 3.00 | 9.96 | 795 | 514 | 2.29 kgf |
| 5.0 | 2.50 | 7.30 | 691 | 447 | 1.59 kgf |
| **6.0** | **2.00** | **5.50** | **588** | **380** | **1.01 kgf** |
| 6.8 | 1.60 | 4.30 | 459 | 296 | 0.64 kgf |
| 7.6 | 1.20 | 2.99 | 283 | 183 | 0.36 kgf |

"Sideways, at the hand" is the push it takes to break the tongue in its weak axis, applied 150 mm
out, which is about where a hand is. Nothing in that column is protected by the detent, because the
detent only resists swing.

**The slit is 6.0, leaving two leaves 2.00 thick.** It is the widest slit whose tongue still takes a
kilogram at the hand. Below it the press gets easier but the arm starts to snap off when a child
picks the robot up by its forearm; above it the press climbs past what a middle-schooler will do
four times in a row.

The slit runs the whole tongue, all 28 mm of it, from the nose to where the limb's rod roots it. The
leaf's 16 mm of free length is the whole reason these numbers work; a slit that stops short of the
root stiffens the joint fast.

#### The press fit force

**5.50 kgf**, both sides together, which is 12 lb. Against the 194.78 kgf the review page found on
the printed elbow, that is a factor of 35.

What sets it is the **teeth**, not the axle. Broken apart at roots 16 and 17 with a 6.0 slit:

- the axle's 0.80 of engagement on its own: 3.37 kgf
- the teeth's 0.40 of climb on its own: 5.87 kgf
- both together: 5.50 kgf

The two do not add. Lifting the ear 0.80 at the pin lifts its neighborhood by more than the 0.40 the
teeth there need, so those teeth come off contact and stop carrying. That also means shortening the
axle buys nothing: at 0.70 of engagement the press is 5.61 kgf, and at 0.60 it is 5.72. The axle can
be sized for retention alone.

Stresses at the worst moment of the press: the ear at **7.6 MPa** and a leaf at **19.4 MPa**, both
against PETG's 50. The old design's ear was at 157.

#### The detent, click and hold

This is a **different load case from the press**, and an earlier section in this file got it
wrong by
treating them as one. Pressing the joint together opens it as a wedge, widest at the tongue's tip,
so only the last tooth in is touching. Turning a seated joint asks **every tooth to climb at once**,
with the axle home in its bore carrying nothing. The two give different forces.

Turning the joint at roots 16 and 17 with a 6.0 slit:

| | |
| --- | --- |
| teeth actually carrying | one, the one nearest the blade's root |
| force to lift it | 64.5 N over both faces |
| breakaway torque, new | **588 N·mm**, or 0.434 ft·lb |
| after the rim wears 0.10 | **380 N·mm**, or 0.280 ft·lb |
| what that is at the hand | 0.40 kgf new, 0.26 kgf worn |
| against the arm's own weight | 22.6 times new, 14.6 times worn |
| ear stress while turning | 10.0 MPa |
| leaf stress while turning | 14.9 MPa |

One tooth carrying is the same result as during insertion, and for the same reason: the members are
beams. Lifting the tooth on the short lever lifts every tooth further out by more than its own
climb, so they ride clear. In rotation the governing tooth is the one on the **leaf's** short lever,
6.89 from the leaf's root, where in insertion it was the last tooth in.

A worn hold of 380 N·mm is 0.26 kgf at the hand. That is a firm nudge, not a knock, which is what a
posable arm should feel like.

#### What breaks first, and at what

| | swing | sideways | twist |
| --- | --- | --- | --- |
| the limb rod, Ø24 | 50.0 | 50.0 | 57.8 |
| the fork, its two ears at 6.8 | 18.4 | 6.2 | 7.3 |
| the blade, a solid tongue | 35.7 | 14.0 | 11.7 |
| **the blade, slit 6.0, leaves 2.00** | **13.0** | **1.1** | **1.2** |

All in ft·lb. The ear is 6.8 thick now instead of 6.4, so the fork gained about a seventh over the
review page's figures.

The weakest thing in the joint is the slit tongue in its weak axis, at 1.1 ft·lb, which is 1.01 kgf
pushed at the hand. Everything else is between five and forty times that. In swing, which is the
axis the joint is for, the detent gives at 0.434 ft·lb and the tongue breaks at 13.0, so the joint
lets go 30 times before anything yields.

The axle shears at 73.9 kgf and crushes its 0.80 of engagement at 32.6 kgf, so with a 5.50 kgf press
it has six times the margin it needs.

#### The roots are worth one more look

Roots 16 and 17 were picked when the model still had a 7.6 slit in it, where they gave 2.99 kgf and
10.3 times the arm's weight held, and 18 and 19 gave only 5.7 times. With the slit rederived, hold
is no longer scarce anywhere, and the roots turn out to be the cheaper lever: they buy softness for
free, because **strength is a section property and does not care where a beam is rooted**, while
stiffness goes as one over the cube of the length.

| roots | slit 4.0 | slit 5.0 | slit 6.0 | slit 7.6 |
| --- | --- | --- | --- | --- |
| 14 / 15 | 14.87 | 11.36 | 8.82 | 5.64 |
| 16 / 17 | 9.96 | 7.30 | **5.50** | 2.99 |
| 18 / 19 | 7.06 | **4.80** | 3.47 | 1.66 |
| 20 / 21 | **5.18** | 3.22 | 2.22 | 0.95 |

Press, in kgf. Sideways strength reads straight off the slit and is the same in every row: 2.29 kgf
at slit 4.0, 1.59 at 5.0, 1.01 at 6.0, 0.36 at 7.6.

So roots 20 and 21 with a 4.0 slit press at 5.18 kgf, a shade easier than the settled pair, and the
tongue takes 2.29 kgf at the hand instead of 1.01. It still holds 268 N·mm worn, ten times the arm.
What it costs is rod: each root pulls the limb's rod back another millimeter, and at 20 and 21 a
little under half of every 48 mm segment is joint rather than rod. That is a look, not a number, and
it is why the shorter pair was chosen.

**Mike decides:** whether to leave the roots at 16 and 17 with a 6.0 slit, or move to 20 and 21 with
a 4.0 slit and buy back the tongue's weak axis. The rest of the design is the same either way.

#### The connector and the names

- The fork's robot connector moves to the fork's end face, where the blade's already is, pointing
  out. It takes Transform's flip out of tutorial 10 and gives both limbs one rule to state. It
  changes tutorials 9 and 10.
- The two parts are named `fork` and `blade`. The page for tutorial 10 stops having to say "Part 2,
  which is the fork" three times.

Both are recorded here only. The CAD is frozen and so is `index.rst`.

#### Where the stale numbers lived

The freeze lifted on 2026-08-30 and all four landed:

- `src/stickbot/make_plans.py`: `GAP`, `STUB_PROUD`, `BLADE_OUT`, `SLOT_DEEP`,
  `EAR_FREE`, `TOOTH_PROUD`, `VALLEY_D`, and the slit, which came out on 2026-08-24 and went back
  in. `VALLEY_DEEP` is gone; the valley is a through hole. `PRESS_F` and `EAR_STRESS` now come out
  of `src/stickbot/hinge_spring.py` rather than being typed
- the hinge plan sheet, which `detail_hinge` draws from those
- the build brief, rewritten whole, and the assembly brief, which both carried 36.3 kgf
- `.docs/reviews/hinge/source/index.rst`, rewritten so that every finding ends in a decision

### Decided: roots 20 and 21 with a 4.0 slit

> Let's go with roots 20 and 21 and a 4.0 slit, does that make the slit tongue stronger?

Yes. Half again in swing, and about two and a third times in the two weak axes:

| the tongue, at its root | 16 / 17, slit 6.0 | 20 / 21, slit 4.0 | |
| --- | --- | --- | --- |
| each leaf | 2.00 | 3.00 | |
| swing | 13.0 | 20.3 | ft·lb |
| sideways | 1.10 | 2.49 | ft·lb |
| twist | 1.24 | 2.79 | ft·lb |
| sideways, pushed at the hand | 1.01 | 2.29 | kgf |

**The slit is doing all of that, not the roots.** Strength is a section property; it does not care
where a beam is rooted. What the longer roots buy is softness, and softness is what pays for the
narrower slit. The two moves have to be made together, which is why the table above only has two
columns and not four.

#### The whole joint at 20 and 21

| | |
| --- | --- |
| `BLADE_OUT`, `SLOT_DEEP` | 32 and 33 |
| `TAB_FREE`, `EAR_FREE` | 20 and 21 |
| the limb's rods | 19 mm on the blade's side, 18 on the fork's |
| the slit | 4.0 wide, the whole 28 mm of the tongue, leaves 3.00 |
| press fit | **5.18 kgf**, both sides, which is 11 lb |
| breakaway, new | **414 N·mm**, 0.306 ft·lb, 0.28 kgf at the hand, 15.9 times the arm |
| breakaway, worn 0.10 | **268 N·mm**, 0.198 ft·lb, 0.18 kgf at the hand, 10.3 times the arm |
| ear and leaf, pressing | 6.7 and 15.0 MPa |
| ear and leaf, turning | 7.9 and 7.7 MPa |
| teeth carrying, turning | two |

Everything else is unchanged: the face at ±5.20, the 0.20 seat, the land and its two ramps, Ø1.2
valleys, a 1.6 cone with a 0.4 flat top, 24 teeth on r 9.109, the axle 1.00 proud.

#### What flips, in the review page's findings

`BLADE_OUT` 32 and `SLOT_DEEP` 33 are exactly the numbers typed in `make_plans.py` today. So the
finding that they were typed where the rule beside them derives them resolves the other way round:
**the typed pair stays and the limb's rods move.** Each rod ends at its root instead of at `NOSE`,
which is 19 mm on the blade's side and 18 on the fork's, out of a 48 mm segment carrying a 9 mm
socket at its far end. A little under half of every segment becomes joint.

`EAR_FREE = SLOT_DEEP - NOSE` is then right as it was originally written, 21 mm, and the
uncommitted edit that made it `NOSE` comes back out. The plan sheet's 21 mm ear was never the thing
that was wrong; the rod was.

#### The axle is back in charge of the press

At 16 and 17 with a 6.0 slit the teeth set the press and the axle's length bought nothing. At 20
and 21 with a 4.0 slit that reverses, because the leaves are thicker and the teeth are softer to
climb than the axle is to lift:

| axle proud | engaged | press | crushes at |
| --- | --- | --- | --- |
| 1.00 | 0.80 | 5.18 kgf | 32.6 kgf |
| 0.90 | 0.70 | 4.53 kgf | 28.5 kgf |
| 0.80 | 0.60 | 4.36 kgf | 24.5 kgf |

Below 0.90 the teeth take over again at 4.19 kgf and nothing more is on offer. The hold does not
move at all, because the axle is home in its bore when the joint turns.

Keep the axle at 1.00 proud. It out-engages the tooth's 0.40 climb by 0.40, which is the margin the
rule asks for, and it crushes at six times the press. Take the 0.90 only if 5.18 kgf turns out to be
too much in the hand, and know that it spends half the axle's margin to save 0.65 kgf.

#### Weakest link, restated

| | swing | sideways | twist |
| --- | --- | --- | --- |
| the limb rod, Ø24 | 50.0 | 50.0 | 57.8 |
| the fork, its two ears at 6.8 | 18.4 | 6.2 | 7.3 |
| **the blade, slit 4.0, leaves 3.00** | **20.3** | **2.49** | **2.79** |

All in ft·lb. The tongue is still the weakest thing in the joint sideways, but by two and a half
times against the fork rather than five and a half. At the hand that is 2.29 kgf against the fork's
5.75. In swing the detent lets go at 0.306 ft·lb and the tongue breaks at 20.3, so the joint gives
sixty-six times over before anything yields.

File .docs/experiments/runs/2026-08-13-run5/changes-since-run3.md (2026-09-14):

# Run 5 — what changed since run 3 built the CAD

Phase 1 of [`../../design-into-cad.md`](../../design-into-cad.md). Derived from
`git diff 5ff5f3d..HEAD -- build-briefs sketches`, where `5ff5f3d` is where run 3's six part
waves landed. Everything below is design that was written after that and never reached a part
studio — run 4 copied run 3's geometry unchanged.

This is the *anticipated* list. The audit in phase 3 is what decides whether each item is really
a delta, and by what route it gets repaired. Nothing here is a measurement.

## Torso

| What | Written | In the CAD |
| ---- | --- | --- |
| shoulder stud direction | 53° below horizontal, 30° toward the front | leaves the side face square |
| shoulder stud root | side face at x = ±18, 4 mm below the top face | side face, on the joint station |
| shoulder stud shape | first 8 mm Ø8 boss coaxial with the stalk, last 5 mm Ø3 stalk, then the Ø6 ball | plain Ø3 stalk |
| shoulder stud length | 13 mm from side face to ball center, ball 6.775 out and 10.382 below the root | ball center at (±23, 0, +24) |
| boss top | cut flush where it crosses the torso's top face | no boss |
| neck boss | Ø12 on the top face, on the axis | never built — plain stalk |
| hip stud | plain Ø3 stalk standing 5 off the bottom face | matches |

The shoulder is the largest single change in the robot and the reason the brief exists: with a
plain 5 mm stand-off the Ø12 upper arm fouls the torso through the first 12.19° of its swing, so
the ±37.09° the joint allows is not available. Acceptance check is the least clearance between arm
and torso across the swing.

## Hinge — both limb halves

| What | Written | In the CAD |
| ---- | --- | --- |
| blade | 5.0 | 3.0 |
| slot | 5.6 | 3.6 |
| ear | 3.2 | 1.2 |
| blade width, the chord | 10.909 at ±2.5 | 11.62 at ±1.5 |
| ear inner chord | 10.613 at ±2.8 | 11.45 at ±1.8 |
| ear outer chord | **gone** — the ear's outer surface is the Ø12 cylinder, there is no outer plane | 10.39 |
| round ends | r6, which is `#limbD / 2` | r5.81 |
| blade stands out | 16, so the blade's own limb stops 10 from the pin axis | rod stops 6.11 from the axis |
| clevis slot | 17 deep from a tip standing 6 out, so the root sits 11 behind the axis | root 6.11 behind |
| slit | **new** — 0.8 wide, 16 deep, down the blade's middle, open at the round end, leaving two tabs of 2.1 | no slit, solid blade |
| detent crest | ±2.2 | ±1.2 |
| detent valley floor | ±2.05 | ±1.05 |
| detent land | ±2.5 | ±1.5 |
| ear face | ±2.8 | ±1.8 |

The detent band r4.40 → 5.20 does not move, and neither does any *difference* in the stack — the
rebalance shifted every station out by the same 1.0. Against an r6 end the rim outboard of the
valley ring becomes 0.70 rather than 0.26.

Why it changed: ear and blade are springs in series, so they carry the same force and split the
movement inversely with stiffness. The as-built 1.2 ear is 16.8× more flexible than the solid 3.0
blade, takes 0.472 of the 0.5 alone, and sits at 46.2 MPa against PETG's 50. The written joint
splits 0.20 / 0.30 at about 19 MPa and presses at 3.2 kgf.

## Foot

| What | Written | In the CAD |
| ---- | --- | --- |
| ankle socket relief slits | four, as on every other socket | **none** — the collar is one unslit cylinder |
| collar length | 7.35 | 7.35 — **a record, not a target.** Do not repair toward 5.5; the plate sets it |
| symmetry about its own fore-and-aft centerline | required, so one part serves both sides | r4 features at (5.14, 5.94) and (7.10, −6.22) are not a mirror pair |
| which axis the length runs along | the brief says Y; the model builds X and the assembly turns it 90° | conflict, not a repair — see phase 4 |

The unslit collar is the one joint on the robot that cannot be assembled: the whole circumference
would have to stretch to pass a Ø6 ball through a Ø5.803 mouth.

## Head

| What | Written | In the CAD |
| ---- | --- | --- |
| socket | bored into the boss face, not a collar | to be confirmed by the audit |
| recess step | 1.0, and it buys 11.4°, not the 42° an earlier draft claimed | 1.0 |
| head center / underside / top | +45.65 / +27.65 / +63.65 | measured at +45.65 in run 4 |

The head's tilt argument needs the torso's neck boss, which was never built. That is a cross-part
dependency, not a head repair.

## Gripper

| What | Written | In the CAD |
| ---- | --- | --- |
| clip bore | 3.3 built; the radial `#fit` convention would give 3.6 | 3.3, measured r1.650 |

Marked `proposed` in the brief and unresolved: the row asks the builder to say which convention was
used and why. Not a repair until somebody decides.

## Limbs

Follows the hinge — the fork now spans the whole limb, and the ear is a slice of the Ø12 cylinder
that thins to nothing at |x| = 5.3066, below one nozzle width over the last 0.231 mm.

## The figure as a whole

The height is no longer a target. r1 set 150 and fitted the stations to it; r2 stacks the stations
and reports the sum, which is **152.65**. Nothing is to be adjusted to make 150 come out. The
run 4 assembly already measures 152.65, so this is a change in what the drawing claims, not in the
geometry.

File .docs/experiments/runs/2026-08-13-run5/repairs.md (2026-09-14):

# Run 5 — repairs

Run 5 changes geometry. Where run 4 copied run 3 and measured it, run 5 opens each part and makes
the model match its brief, one step at a time, measuring after every step. This file is the record
of what was cut and what it measured afterwards. The plan it follows is
[`../../design-into-cad.md`](../../design-into-cad.md).

Every number here came off solved geometry. Nothing is read back from a feature parameter, because
a parameter read-back and a tree of `OK` states have each passed separately on an edit that moved
nothing. S1 through S3 measured through `POST .../featurescript`; by S4 that endpoint was returning
429 and the numbers come from `massproperties`, `boundingboxes` and rendered views instead.

## S1 — the torso's shoulder stud

The brief asks for a stud that leaves the side face at 53° below horizontal and 30° toward the
front, 13 mm from the face to the ball center, whose first 8 mm is a Ø8 boss coaxial with the
stalk. Runs 3 and 4 carried a plain Ø3 stalk leaving the side face square.

**The profile.** Rebuilt as boss, stalk and ball on one axis: six entities in the loop plus the
side face kept as a construction line, so the brief's 13 mm and 8 mm are dimensioned from the face
rather than from the origin.

**Getting it onto the axis.** `STUD_D` is `R_z(−30°) ∘ R_y(+53°)` applied to `+X̂`, so the stud is
two rotations of a profile drawn flat, not one general rotation. Two mate connectors at the root
supply the axes — one turned `ABOUT_X` by −90° to aim its Z along +Y for the drop, one left along
+Z for the swing — and two `transform` features of type `ROTATION` turn the revolve about them.

**The boss runs 8 mm back as well as 8 mm forward.** The first attempt rooted the boss's back cap
at the side face, and the rotation put exactly half the Ø8 disc outside x = 18: a flat crescent of
25.133 mm² on the outside of the shoulder, which is π·4²/2. Running the boss back into the torso
puts that cap inside the block. There is no shorter boss that avoids the cut — a cap fully inside
x ≤ 18 needs at least 6.55 mm of back, a cap fully below z = 24 needs at most 1.99 mm, and those
cannot both hold. **The flush cut is part of the design, not a repair to it.**

**The cut.** Everything standing above the top face is removed by one extrude, `Trim above the top
face`, on a sketch of two circles on the Top plane: Ø80 outside, Ø12 around the neck. The Ø12
leaves the neck stud standing and nothing else — above z = 24 the shoulder material starts at
x = 10.4, so the annulus clears it by a wide margin. The cut starts 24 mm up and runs 40 mm.

It has to sit **after** the shoulder fillets. The fillet at the boss-to-torso junction is concave,
so it *adds* material, and that flare is most of what stands proud; cutting before it just lets it
grow back. A first attempt used the torso's own footprint as the profile and left the outboard
part of the flare behind, out to x = 25.583, because the footprint stops at x = 18.

### Measured after S1

| | |
| --- | --- |
| bodies | 1 |
| volume | 42890.161 mm³, of which the trim took 300.797 |
| shoulder ball centers | (±24.775, −3.912, +9.618) |
| neck ball center | (0, 0, +29) |
| hip ball centers | (±12, 0, −29) |
| highest point that is not the neck | z = 24.000 |

The mirror carried the rotated stud without a further edit.

### What S1 found

- **The brief put the shoulder ball 4 mm too high.** It read `z = +13.618`, which is 24 − 10.382 —
  measured down from the top face instead of out from the root at z = +20. Corrected to `+9.618`,
  which is what the model measures.
- **The scar rule was stated per mm of diameter and is per mm of radius.** The brief's own 14.64 mm
  for a Ø8 boss is 3.66 × 4, not 3.66 × 8.
- **The swing arc is not free.** The brief claimed the arm clears the torso everywhere in the arc,
  at 0.73 mm at the tightest. Swept properly, the arm clears at rest — 0.776 mm at the zero pose,
  reading it as a plain Ø12 rod — but its far end crosses the torso from 33.38° of the 37.09° the
  ball allows, and at full tilt the deepest overlap is 1.597 mm, 24 mm out along the arm, with 85%
  of directions still clear. The shoulder end itself never binds: 1.372 mm at rest, 0.413 mm of
  overlap at the worst point of the cone. What limits the pose is the arm crossing the body.
- **The neck boss cannot buy the tilt it exists for, so it is not built.** A boss of height `h` on
  the top face makes the boss-to-boss spacing `3.65 − h`, away from the 4 mm the head's 42°
  assumes; and the contact that binds is the head's outer underside at radius 23.43, which a boss
  at radius 6 does not move. Both briefs now say so.

## S2 and S3 — the hinge's two halves

Repaired as a pair, because the surfaces in
[`deconflict.md`](deconflict.md) are shared between them. Every one of these was an existing
dimension driven to a new value; only the slit is a new feature.

### Measured after S2, on `limb-socket-clevis`

| | |
| --- | --- |
| ear inner faces | y = ±2.8, from a slot driven 3.6 → 5.6 |
| ear outer faces | none — the ear's outer surface is the Ø12 cylinder |
| stub tips | y = ±2.0, on the pin axis at z = −24, r 1.0 |
| fork tip | z = −30.000, off a round end driven Ø11.62 → 12 |
| slot root | z = −13.000, which is 11 behind the pin axis |
| volume | 2040.644 mm³ |

The ±2.5 planes that S2b expected to remove with the ear survive, and they are not the ear: they
sit at z −4.15 to −1.957, up in the socket collar, and they are the relief slits. S2b is done.

The stub pins followed the ear face out to y = ±2.0 without being touched — they are constrained
to it rather than dimensioned from the origin, which is what the brief asks for and what let one
edit carry two surfaces.

### Measured after S3, on `limb-blade-ball`

| | |
| --- | --- |
| blade faces | y = ±2.5, from a blank driven 3 → 5 |
| valley floors | y = ±2.05, which followed the blade face on their own |
| pocket floors | y = ±1.5 |
| slit faces | y = ±0.4, leaving a **2.1** tab a side and **1.1** behind each pocket |
| blade tip | z = +6.000, off a round end driven Ø11.62 → 12 |
| the blade's own limb | starts at z = −10.000, so the blade stands 16 out |
| volume | 1949.102 mm³, of which the slit took 141.166 |

Both halves now agree at every surface `deconflict.md` lists.

### The blade's limb ending is not in the sketch that draws the blade

S3c reads as one step and is two features. `Blade profile` carries the profile's own 6.11, and
driving it to 10 moved nothing at all — the volume did not change by a thousandth, because the
blade blank is trimmed back to the limb and everything past the trim is thrown away. The station
that had to move is the `Limb` extrude's **starting offset**, and its depth has to come down by
the same amount or the limb grows out of its far end. Both were needed: the profile has to reach
z = −10 for the blade to meet the limb there.

### What the slit is

`Slit profile` is a rectangle on the **Right** plane, symmetric about the Front plane by
constraint, its root dimensioned **10** below the Top plane — the same 10 the tab cantilevers —
and 0.4 from the mid-plane. `Slit` extrudes it Remove, Symmetric, **Through all**, so nothing in
the feature depends on how wide the blade happens to be.

The rectangle's top is dimensioned 8 above the Top plane and that number is not a design
dimension. It is an overshoot. The round end reaches z = +6 at one point only, so a profile that
stopped at 6 would touch the surface and leave the slit closed at the tip instead of open.

## S4 — the foot

Two steps that share nothing: a re-sketch that turns the whole part 90°, and four slits cut into a
collar that already existed.

### S4a — the outline now runs along Y

`Foot outline` is a heel circle Ø16 and a toe circle Ø24 joined by two lines. Both centers are
constrained onto the Right plane's trace and the two side lines carry a `Symmetric` about it, so
the width is one dimension rather than two. The lines were left un-tangent here and S7 fixed that —
see below. Every feature downstream — plate, fillet, ball,
collar, socket, ribs — followed the new orientation without being re-picked, except the sole rib
profile, which had been drawn 26 × 3 along X and had to be transposed.

### Measured after S4

| | |
| --- | --- |
Stated after S7 turned the part around and constrained the outline, which is the shape that ships.

| | |
| --- | --- |
| bodies | 1 |
| width, along X | ±12.000 |
| length, along Y | −32.000 to +16.000, toe forward |
| height | −12.000 to +1.350 |
| plate | z −12 to −6 |
| collar | 7.350 proud, to z = +1.350 |
| sole ribs | 7 of them, 6 apart, cutting 1 mm up from z = −12 |
| volume | 4899.224 mm³, of which the four slits took 46.048 |

### S4b — the slits

`Relief slit profile` is one rectangle on the Top plane, 0.8 wide by `Symmetric` about the Front
trace, its inner edge dimensioned **2.5** from the origin and its outer edge **6.0**. The 2.5 is
inside the 2.901 mouth radius, which is what lets the mouth open;
[`../../build-briefs/ball-and-socket.md`](../../build-briefs/ball-and-socket.md) gives 2.5 out to
6.0 as the working band. `Relief slit` extrudes it Remove, 6 down and 1.35 up, merge scope the foot
alone so the cut cannot reach the ball. `4 relief slits` is a **feature** pattern of that extrude,
360° and 4 instances, about the collar's own rim edge.

### What S4 found

- **A patterned Add that touches nothing fails quietly, per instance.** `Sole ribs` marched its
  instances −Y off the heel end and landed one rib, with no error anywhere in the tree. This is the
  failure [`../../build-briefs/torso.md`](../../build-briefs/torso.md) warns about, met on a part
  that brief does not cover. Onshape also **rejects a negative pattern distance** outright — the
  field turns pink — so the way back is the flip-direction icon, not a minus sign.
- **A model edge is pickable as a dimension reference even with imprinting off.** The slit's inner
  dimension anchored itself to the collar's outer circular edge instead of the Right plane's trace,
  which put the slit 2.5 mm outside the collar while reading 2.5 in the field. It was re-dimensioned
  from the origin point.
- **A drag test is not a constraint test, and S4a got this wrong.** The outline's two side lines
  never turned black, and a 76 px drag moved nothing, which was read here as "blue but rigid". They
  were under-defined: chords, not tangents, held in place only by where they happened to be
  solved. The drag was resisted by the solver's preference for the current solution, not by a
  constraint. S7 flipped the outline's dimensions and the lines re-solved into a shape 0.322 mm too
  wide, which is how it was caught. **Blue means under-defined. Believe the color, not the drag.**
- **The slit's depths were right and its directions were not, and only the volume said so.** The
  extrude read Blind 1.35 with a second end of Blind 6 — 7.35 in total, exactly the collar's proud
  length — but the first direction ran down and the second ran up, so the pair spanned z −1.35 to
  +6 and half of it was in empty air. The tree was green, the dialog read correctly, and the front
  render showed a notch that could pass for foreshortening. What caught it was arithmetic: a cut
  through that annulus over z ±1.35 is 3.45 mm³ and over the whole 7.35 is 11.51, and the model had
  given up 3.457. Swapping the two depths — 6 down, 1.35 up — gave 11.512.
- **`Direction` in the extrude dialog is not a flip.** It is a checkbox that asks for a direction
  *reference*, and ticking it with nothing to reference errors the feature. The flip is the arrow
  beside the `Blind` dropdown.

## S5 — the brief was wrong, and it is fixed

`hinge.md` said run 3 built 13 valleys across the blade's 180°. Measured on the model: 24 valleys
on each face at exactly 15° spacing, spanning the full 360° — and the feature that cuts them is
named `24 detent valleys`. The brief now says what the model does.

## S7 — the assembly

Fourteen instances of six parts, every one inserted from its `run 5` version rather than a
workspace.

### The robot faces −Y and the foot points +Y

Nothing in [`../../build-briefs/README.md`](../../build-briefs/README.md) says which sign of Y is
forward. It says only that fore-and-aft is Y, and each brief then picked a direction on its own.
Two picked −Y and one picked +Y, and no part ever measured against another until they were put in
one assembly.

The head decides it. Its bounding box runs y −16.5 to +15.0: the flat back face that Shell opens is
at +15, the profile front is at −15, and the −16.5 is the eyes standing 1.5 proud of it. The torso
agrees — S1 measured the shoulder ball at y = −3.912, and `torso.md` calls that "forward". Onshape's
own Front view looks at the −Y side, so a robot that faces −Y is the one whose front elevation is
the Front view.

The foot is the outlier. It measures y −16 to +32, heel behind and toe in front of a **+Y** front,
and [`../../build-briefs/foot.md`](../../build-briefs/foot.md) states that choice in as many words.
So the figure as first assembled stands with its feet on backwards.

This is the second orientation fault found in the same part in two steps, and it has the same root:
**a shared convention that no single brief owns gets decided independently by each part, and the
error is invisible until they meet.** S4a caught the axis; S7 caught the sign. `README.md` now
states the sign, because that is the file the parts share.

### Turning the foot around, and what it exposed

The foot is symmetric about its own fore-and-aft centerline, so the turn is a mirror of four
numbers in `Foot outline` and nothing else: the Ø16 and Ø24 swap ends, and so do the 8 and the 20
that place their centers. **No entity had to be dragged across an axis** — swapping which circle is
which does the mirror, and every intermediate state stays solvable if the far circle is moved out
before the near one is moved in.

Two features did not follow:

- **The sole ribs kept marching the way they always had**, which was toward the heel once the heel
  changed ends. `Sole rib profile` moved from 10 to 26 off the centerline, which is the mirror of
  its old station, and the seven ribs land back across the whole sole.
- **The outline came back 24.322 wide instead of 24.** The two side lines were never tangent —
  they were chords whose endpoints happened to sit near the tangent points, and re-solving the
  dimensions moved them somewhere else that satisfied everything the sketch actually said. Two
  `Tangent` constraints turned the whole outline black and the width to exactly 24.000.

The width is the check that caught it, and it caught it only because `boundingboxes` is exact:
the head measures 36.000 across and −16.5 to +15.0 in Y, both to the thousandth, on a part made
of arcs and fillets. **A bounding box that disagrees with the brief by 0.3 mm is a real defect,
not tessellation noise.**

### Measured after mating

| What | Got |
| ---- | --- |
| mate features | 13, all `OK`; 2 assembly mate connectors |
| ground | z = −89.000 |
| top of head | z = +63.650 |
| figure height | 152.650 |
| torso, on its own | x ±27.775, y ±12.000, z ±32.000 |
| hips | z = −29, knees −53, ankles −77 |
| shoulder balls | x ±24.775, y −3.912, z +9.618 |
| volume, all fourteen instances | 75512.993 mm³ |

### What the assembly found

- **A mate that reports 200 on creation can still be in error, and the reason is the query
  type.** Eleven mates were posted with `BTMIndividualQueryWithOccurrence-626` and a path of
  `[instance id, mate connector id]`. Onshape accepted every one, rewrote the type to
  `BTMIndividualOccurrenceQuery-626`, and set all eleven to `ERROR`. Hovering the error icon in
  the tree gives the message the API withholds: `Mate cannot resolve mate connectors.` A part
  studio's mate connector is `BTMPartStudioMateConnectorQuery-1324`, whose `path` is the
  occurrence alone and whose `featureId` is the connector. An assembly's own mate connector is
  `BTMFeatureQueryWithOccurrence-157`, with an empty `path`. The way to learn either is to build
  one mate in the GUI and read the feature back.
- **The dialog named both connectors while the mate was broken.** Opening the failed mate showed
  `Neck socket` and `Neck` in its list, in red. The names resolve off the ids; the mate resolves
  off the query type. **A filled dialog is not a working reference.**
- **The torso's `Shoulder R` and `Shoulder L` connectors are not on the shoulder balls.** They sit
  at x ±23, y 0, z +24 — the square-stud stations from before S1 — and Onshape's readout says so
  when the connector is selected. The balls S1 built are at x ±24.775, y −3.912, z +9.618, so the
  connectors are 14.382 too high, 1.775 inboard and 3.912 behind. S1 moved the geometry and left
  the connectors where they were. Two new mate connectors were placed on the ball faces in the
  assembly, which needs no new version of the torso and does not disturb the eleven mates already
  referencing it.
- **Nothing was fixed, so a drag moved the whole robot.** A mouse drag aimed at posing an arm
  landed on empty space, and the assembly — every instance of it, mates and all — translated
  37.292 in x and 12.012 in z. The mates stayed `OK` the whole time, because a rigid translation
  of everything satisfies all of them. Undo put it back; `Fix` on the torso stops it happening
  again.
- **The assembly matches `make_plans.py` and the shared README's station table does not.**
  `make_plans.py` computes `HIP_Z` −29, `KNEE_Z` −53, `ANKLE_Z` −77, `SOLE_Z` −89, `HEAD_T` 63.65
  and `HEIGHT` 152.65, and the assembly measures every one of them. The table in
  [`../../build-briefs/README.md`](../../build-briefs/README.md) says hip −24, knee −48, ankle −72
  and ground −84, which is a 5 mm shift from the first joint down. The parts are right and the
  table is stale.
- **Both shoulders are ball mates, so the arms rest wherever the solver leaves them.** After
  mating, the left arm stands out level and the right hangs down with the hand turned forward.
  Neither pose is a fault and neither is chosen; the joint has three rotational degrees of
  freedom and no limits.

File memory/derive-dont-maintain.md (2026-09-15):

---
name: derive-dont-maintain
description:
  "Never write down a count, list or summary that a grep or a few lines of Python can produce —
  storing it creates permanent maintenance for no information."
metadata: 
  node_type: memory
  type: feedback
  originSessionId: c7e95b50-7b3c-4747-a656-ece9f33b51c4
  modified: 2026-08-13T02:29:10.664Z
---

**If grep, `git ls-files`, or a few lines of Python can produce it, do not write it down.** A
stored count or list is a second copy of a fact, and every change to the real thing now has to
be mirrored into it by hand or it goes stale and lies.

The user (Mike) framed it: *"don't make work by counting and listing things that can be found with
simple grep, python techniques, because we're making work by always maintaining the count — it's
part of the stay DRY."*

**Sizes are the worst case, because they read as helpful.** "a 287-line how-to", "roughly 1,200
lines of reading", "the contract, 101 lines", "a 619-line Sphinx page". Every one of these is
`wc -l` frozen into prose, wrong the next time the file is edited, and useless to the reader
while it is right — nobody decides anything differently because a document is 287 lines. Written
2026-08-12, immediately after writing this memory: I cited a how-to as 283 lines, discovered it
was 287, and *corrected the number* instead of deleting it.

**A document must not tally its own contents.** "Eight findings, all fixed", "Drawing them found
four things", "Findings 7 and 8 above", "How findings 1 to 4 were fixed", "the three `study-`
renders", "Run 2's two renders" — every one of these has to be edited the moment the document grows,
and editing it is not progress. The user (Mike), 2026-08-12, after watching it happen through three
successive commits: *"You keep on counting things, that don't need to be counted, and then editing
the counts. I need you to stop doing that!"*

The replacements are always available and always shorter: *"Every finding below is fixed"*,
*"the findings above say which ones came this way"*, *"the `study-` renders"*. Numbered headings
already carry the count for anyone who wants it.

This is the general rule behind the specific ones already recorded: no counts on drawings
(see [[drawing-conventions]]), and never restate a fact another file enforces
(see [[one-fact-one-home]]).

**How to apply:**

- Prefer a pointer and the command over the answer: say where the parts are and how to count
  them, not "eight parts, fourteen instances".
- Enumerations of structure go stale fastest — a list of a file's sections needs editing every
  time the structure changes.
- This governs replies to the user too. Producing an inventory nobody asked for is the same
  work-making, and it costs context on both sides.
- It does not forbid a measured number that came from an actual measurement and is cited as
  evidence. A cavity volume of 109.48 mm³ is a finding. "Six unique parts" is a count.

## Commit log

2026-09-14 First commit: the text of the CAD course, without the capture
    Carried from the sponge repository, which stays on disk as the archive
    and keeps its own history. 1,479 files, 27 MB: the contract under
    .claude/, tools/, the build specification under .docs/build/, every run
    folder's plans, notes, registers, logs and reference JSON, the design
    source in instructions/robot-guide/, and draft9p4's 20 source files
    plus 22 toolbar close-ups.
    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
    [ball-stud.stl, l-limb.stl, socket.stl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]
2026-09-14 Correct the plan's LFS reading and record Phases 1 and 2
    The plan said Git LFS was not needed and would make things worse. The
    old repository already uses it: .gitattributes routes *.png and *.mp4
    through LFS, 12,989 tracked files are LFS-managed, and that is why its
    pack is 129 MB while .git is 1.5 GB. LFS was working. The repository is
    large because 12,977 screenshots were committed.
    The new repository still needs nothing — 22 toolbar close-ups, largest
    file of any kind 2.12 MB — and deliberately inherits no routing rule.
    The decision is owed when draft9p5 publishes frames, and two things have
    to be established first: what GitHub Pages does with an LFS-tracked
    image, and what this acc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
2026-09-14 Constitution 5.2.0: the Capture is out gate, and Phase 3's repointing
    The gate that Phase 1 built had no entry in the contract, which is the
    documentation gap the constitution calls a defect. The Quality Gates
    table gains Capture is out, and the Archive section gains the second
    archive: sponge holds the 12,977 frames, the six superseded guide
    drafts and its own history, so a record here naming a file this
    repository does not have is pointing there.
    Exercised before it was written down. check_images.py refused a PNG
    force-added outside a guide's source/images/ and a 5.7 MB file, naming
    each and its reason, and went green once both were untracked.
    Phase 3's repointing. The carry broke fourte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
2026-09-14 Add Phase 3.5: re-root before Phase 4, and prove the new root
    Phase 4 is the largest piece of work left, and a session rooted in the
    wrong repository reads the wrong contract with nothing in the injected
    text to say so. Switching first also tests the move while it is cheap
    to fix.
    sponge's constitution is 5.1.0 and this one is 5.2.0, so the Version
    line is an unambiguous test of which repository a session is reading.
    Also records that draft9p4's own plan does not govern Phase 4. It is a
    guide-draft plan: it claims Steps reproduce, forbids REST from building
    the model, and ends in fourteen written pages. Phase 4 does none of
    those, so it needs its own plan and draft9p4's is agreed deactivat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
2026-09-14 Carry tutorial 9's take log from the sponge archive
    580 lines recording what was built in the hinge tab and what each step
    found. It was never committed in sponge, and it is the last piece of
    work that existed only there.
    Its 208 frames stay behind. They are capture for a page draft9p4 will
    not write now that it is the reference model rather than a guide draft.
2026-09-15 Review the memories against the move
    Twenty-nine memories were copied byte-identical into stick-e-bot's
    project directory. This records what to do to each and why.
    Nothing is deleted; every memory still carries a rule or an observed
    fact that holds. Two need rewriting, and one of those turns on a
    question only Mike can answer.
    The one with teeth is limbs-are-twelve-mm-cylinders. Its relation is
    right and its number is not: #limbD is #torsoH / 4, #torsoH is 96 mm,
    so the limb is 24 mm across and not 12 mm. The design went to 2x and
    the memory did not.
    Reported alongside, not fixed: robot-build-plan.md opens by calling
    this a 150 mm articulated figure while its own line 713 says the 150 mm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
2026-09-15 Constitution 5.3.0: the memories move into the repository
    They were in the harness's own store under
    ~/.claude/projects/<slug>/memory/, keyed to the working directory. They
    are project knowledge — settled numbers, habits that cost a run, tools
    that behave unlike their documentation — so they belong with the
    project. Moving to stick-e-bot is what surfaced it: that store is keyed
    to the old path and does not follow.
    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
2026-09-15 Delete limbs-are-twelve-mm-cylinders; the design source already says it
    Everything in it is in .docs/robot-build-plan.md, Stage 5 — Limbs, said
    correctly: every limb is a #limbD cylinder, Ø12 at the 48 mm robot and
    Ø24 at this one, joints sized to fit inside it and never the limb grown
    to fit a joint, and the four routes as teaching tools rather than
    sections with each row marked "no home". Lines 346 to 352 carry the
    reasoning the memory kept.
    So the memory was a second copy that went stale while the original
    stayed true, which is what one-fact-one-home and derive-dont-maintain
    exist to prevent. It was wrong twice over: Ø12 mm at #torsoH 96 mm, and
    its own closing claim that the decisi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
2026-09-15 Constitution 5.4.0: write and fix only the live draft
    The rule existed only in a memory, one-guide-is-the-end-state, whose own
    facts had gone stale — it named robot-guide4 as the live guide, and
    robot-guide4 stayed in the sponge archive. Checking it the way
    limbs-are-twelve-mm-cylinders was checked found the opposite answer:
    that one duplicated the design source and was deleted, this one was the
    only copy of a rule no file carried. Nothing in the Constitution said
    not to edit a superseded draft.
    So the rule moves into § Where developmental draft products live, and
    the memory goes.
    Also: trust-mike-or-read-the-docs becomes
    trust-the-user-or-read-the-docs, finishing what 5.3.0 started;
    ag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
2026-09-15 Close the memory review's path repoints and dangling links
    numbers-carry-units names .claude/rules/parts/prose-style.md, the path
    since 5.1.0.
    feature-edits-apply-live linked [[bodydetails-beats-featurescript]] and
    the file is onshape-bodydetails-beats-featurescript, so the link
    resolved to nothing. Every [[link]] in memory/ now resolves.
    drawing-conventions linked [[robot-plan-sheets-are-generated]], a memory
    never written. The fact it gestured at lives in the repository —
    instructions/robot-guide/make_plans.py renders every plan drawing and
    ninja plan runs it — so it points there instead of inventing a second
    home for it.
    Carries Mike's two edits: no-invented-gates and
    instructions-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
2026-09-15 capture-while-you-experiment stops arguing against the capture gate
    Its Why rested on the 17 debugging screenshots being "discarded with
    the scratchpad", offered as the loss. Since the Capture is out gate the
    scratchpad is where capture belongs, so that sentence read as an
    argument against a rule the Constitution now carries.
    The fault was never where they lived. It was what they were for: framed
    for reading rather than for use on a page, so none of them was ever a
    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
2026-09-15 robot-build-plan.md stops stating a height it does not build
    Mike's change, moved over from the sponge working tree where it was
    written.
    The opening line said "A 150 mm articulated figure". make_plans.py
    computes HEIGHT as 318.0 mm from TORSO_H 96, and says in its own
    comment that nothing is fitted to a target height. The line now
    describes the figure as about 300 mm tall and says the program
    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
2026-09-16 Constitution 5.5.2: delete session-state.md
    Run 2 is overcome by events. The file was a snapshot titled "end of
    run 2" whose design section is settled twice over since — Ø12 limbs,
    grip 1.35, "round bumps beat wedges" — and whose conventions are now two
    ninja check gates, two memories and the Branch Policy.
    It was spared once, in reorganization-plan.md, on the ground that it was
    the only registry of the robot's Onshape ids. It was not. Every did,
    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
2026-09-16 Delete reorganization-plan.md; every phase is done
    All thirteen phases were marked Done, and the one table row held back —
    session-state.md — was carried out on 2026-09-16. What remained was
    history: the pre-reorganization state, the traps of executing the move,
    and the uv and codespell setup, whose one live gotcha is already in
    check_spelling.py's docstring.
    Two of its Decisions taken had been reversed and would have misled
    anyone reading it. Decision 2 said instructions/ holds the built site as
    well as the source; the Capture is out gate refuses tracked Sphinx
    output. Decision 1 named robot-guide/source/index.rst as Session 1; that
    directory is the design source now. Decisions 3 and 4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
2026-09-16 Constitution 5.6.0: Define success holds for all work, not just lessons
    Mike's rewrite. "Define success, then loop until it is verified" becomes
    "Define success and initial steps, then loop until successful", and the
    body stops being about documents with readers.
    It used to say "say what the reader or student can do at the end, not
    what steps exist" — a general title over a body that defined success
    only for teaching material, so the rule had no operative content for a
    part, a script, an audit or a fix. Every other Working Rule holds for
    code, prose, CAD and a conversation alike; this one did not.
    "initial steps", not "a plan": plan is a loaded word beside the
    active-plan pointer rule an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
2026-09-16 Constitution 5.6.1: no document targets how long the figure takes to CAD
    The number had no owner. lesson-design advertised "the eight-hour clock"
    in its frontmatter and said nothing about it in its body, and 5.6.0 had
    just removed the Constitution's only statement of it as out of altitude
    for a Working Rule. A target named in three summaries and defined
    nowhere is not a constraint.
    Removed: the duration from README.md, .docs/project.md and
    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
2026-09-16 Stop restating the project in .docs/project.md and .docs/README.md
    The top-level README says what the course is. Anyone who wants to know
    looks there, so saying it again here — or pointing at it — is the same
    duplication.
    project.md loses § What we're building. Its first paragraph restated
    the README, and its second half argued which features the figure
    teaches and in what order, which is robot-build-plan.md's job; the
    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
2026-09-16 Stop describing the retired sponge pipeline as if it were here
    .docs/experiments/spongebob-guide/ did not carry to this repository —
    the Phase 2 list dropped it, and the Constitution already called it
    retired. Six places went on describing it in the present tense.
    .docs/README.md loses § The guide entire, the "state of play for the
    sponge" paragraph, and the sentence naming the generated Sphinx guide
    as the retired pipeline. It also loses two bullets that made
    spongebob-guide/content.py "the single source of truth for words" and
    pointed at its docstring for the full prose rules — a file this
    repository does not have. The voice rule itself survives in the
    write-for-students-who-will-suc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
2026-09-16 prose-style 5.7.0: a voice rule for student-facing text
    Playful, never judging, never talking down. A number belongs to the
    thing it measures, never to a person.
    The rule existed in exactly one place — a bullet in .docs/README.md
    that also named spongebob-guide/content.py as the authority on it —
    and 96f650a took it out with the retired pipeline. Grepping
    .claude/rules/ and .claude/skills/ for playful, talking down, judging,
    tone, voice and light-hearted returns nothing, so it had never been in
    the contract; removing the bullet left it stated nowhere that binds.
    Two memories touch it and neither carries it.
    write-for-students-who-will-succeed has "light-hearted" only in its
    frontmatter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
2026-09-16 Expunge SpongeBob from the repository
    git grep -i spongebob now returns nothing. Eleven occurrences across
    seven files, plus two calling the retired model "the sponge".
    The experiments' Onshape ids go with it. .docs/project.md loses the
    CAD Class — SpongeBob reference block with its document, workspace and
    part-studio ids, and the three-row debris table with theirs. Nothing in
    this repository pointed at any of them.
    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
2026-09-16 Say "the archive" instead of naming the old repository
    git grep -in sponge over live files now returns nothing, and no
    document depends on what the archive directory is called — so renaming
    it is yours to do whenever, with nothing to repoint afterwards.
    Sixteen lines across eleven files. The Constitution's Archive section
    says the older archive "sits beside this one on disk" rather than naming
    it; everywhere else reads "the archive" or "the old repository".
    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
2026-09-16 Note which figures must be generated and which must not
    A drawing that explains a dimension rots two ways: the picture stops
    matching the design, or the picture is redrawn and the sentence above
    it goes on claiming what the new picture disproves. The second is worse
    — a correct drawing under a false heading looks checked.
    The pattern already exists for one subsystem. reviews/hinge's
    make_figures.py imports make_plans and hinge_spring and emits eleven
    SVG figures and five .rst tables straight into the Sphinx source;
    ninja hinge-figures regenerates the lot and nothing in it is typed. The
    three studies in experiments/sketches/ are the same kind of drawing
    built the other way, importing only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
2026-09-16 Constitution 5.8.0: phases 2 and 3, and the gate that holds them
    The hinge review's three figure generators and nineteen run scripts
    import stickbot and drop their sys.path lines. Draft9p4's thirteen lose
    the absolute paths they were reading modules through and writing output
    into — a different checkout, silently, which is the whole reason for
    this work.
    The new Quality Gate, Imports installed, is what keeps it. An installed
    package makes import mean the same thing from any directory, and one
    sys.path.insert undoes that without a symptom: the wrong module imports
    fine. Four run folders that finished before the package existed are
    named as exempt, their scripts being a record of what was d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
